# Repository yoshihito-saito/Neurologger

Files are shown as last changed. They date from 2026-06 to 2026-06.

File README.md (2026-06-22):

# WILD

**WILD** (Wireless, Interactive, Lightweight Datalogger) is an ultra-lightweight multimodal neurologger for long-term neural and behavioral recording in freely behaving animals. It combines local neural data logging, behavioral sensing, onboard processing, and responsive stimulation in a head-mounted platform designed for naturalistic and multi-animal experiments.

## Documentation

The documentation portal is built with MkDocs Material and is maintained through Markdown files in [`docs/`](docs/).

- [Getting Started](docs/getting-started/index.md)
- [Hardware](docs/hardware/index.md)
- [Software](docs/software/index.md)
- [Analysis](docs/analysis/index.md)
- [Community](docs/contributing.md)

## Platform Scope

- Local microSD electrophysiology recording with BLE-based control, synchronization, status, and low-bandwidth preview
- Closed-loop stimulation through embedded DSP and curated TinyML pipelines
- Current open-source 64-channel workflows, with Neuropixels-compatible and active-probe variants documented separately as research targets
- IMU, ultrasonic audio, camera, and digital event recording
- TinyML inference support through validated release-integrated models
- Long-term recording and multi-animal experiment workflows

## Repository Layout

| Path | Purpose |
| --- | --- |
| [`docs/`](docs/) | MkDocs documentation source |
| [Latest GitHub release](https://github.com/ayalab1/Neurologger/releases/latest) | Prebuilt device release images |
| [`Software/`](Software/) | WILD Console installers |
| [`Code/`](Code/) | MATLAB and Python analysis scripts |
| [`PCB/`](PCB/) | PCB fabrication and assembly files |
| [`3Dprint/`](3Dprint/) | Mechanical parts and CAD files |

## Local Documentation Build

```bash
pip install -r requirements.txt
mkdocs serve
```

The GitHub Pages workflow builds the site with:

```bash
mkdocs build --strict
```

## License

See [LICENSE](LICENSE).

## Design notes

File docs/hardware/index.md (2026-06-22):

# Hardware

Hardware documentation covers the WILD device architecture, onboard sensors, optional modules, mechanical assembly, power choices, and release-image compatibility for supported device revisions.

<div class="wild-grid wild-nav-grid">
  <a class="wild-card wild-card-link wild-card-compact" href="device-overview/">
    <div>
      <h3>Device</h3>
      <p>Architecture</p>
    </div>
  </a>
  <a class="wild-card wild-card-link wild-card-compact" href="onboard-sensors/">
    <div>
      <h3>Sensors</h3>
      <p>IMU, audio, camera</p>
    </div>
  </a>
  <a class="wild-card wild-card-link wild-card-compact" href="opto-module/">
    <div>
      <h3>Opto module</h3>
      <p>Stimulation</p>
    </div>
  </a>
  <a class="wild-card wild-card-link wild-card-compact" href="usb-board/">
    <div>
      <h3>USB-GPIO</h3>
      <p>Trigger alignment</p>
    </div>
  </a>
  <a class="wild-card wild-card-link wild-card-compact" href="mechanical/">
    <div>
    <h3>Mechanical</h3>
      <p>Mounts and enclosures</p>
    </div>
  </a>
  <a class="wild-card wild-card-link wild-card-compact" href="power/">
    <div>
    <h3>Power</h3>
      <p>Battery, SD, mode power</p>
    </div>
  </a>
  <a class="wild-card wild-card-link wild-card-compact" href="https://github.com/ayalab1/Neurologger/releases/latest">
    <div>
      <h3>Releases</h3>
      <p>Firmware images</p>
    </div>
  </a>
</div>

## Hardware Asset Map

| Hardware area | Repository path |
| --- | --- |
| Datalogger PCB | [PCB/Datalogger](https://github.com/ayalab1/Neurologger/tree/main/PCB/Datalogger) |
| Opto module | [PCB/Optomodule](https://github.com/ayalab1/Neurologger/tree/main/PCB/Optomodule) |
| Camera unit | [PCB/CameraUnit](https://github.com/ayalab1/Neurologger/tree/main/PCB/CameraUnit) |
| USB-GPIO board | [PCB/USBboard](https://github.com/ayalab1/Neurologger/tree/main/PCB/USBboard) |
| USB-GPIO firmware | [Firmware/WILD_USB_GPIO.hex](https://github.com/ayalab1/Neurologger/blob/main/Firmware/WILD_USB_GPIO.hex) |
| Opto-module firmware | [Firmware/Opto_module.hex](https://github.com/ayalab1/Neurologger/blob/main/Firmware/Opto_module.hex) |
| Mechanical parts | [3Dprint](https://github.com/ayalab1/Neurologger/tree/main/3Dprint) |
| Battery table | [LipoBattery_selection.csv](https://github.com/ayalab1/Neurologger/blob/main/docs/LipoBattery_selection.csv) |
| Prebuilt device images | [Latest GitHub release](https://github.com/ayalab1/Neurologger/releases/latest) |

## Manufacturing Workflow

For a new WILD device build, start with the [Fabrication](../fabrication.md) page. The workflow covers fabrication parameters, PCBA submission, special components, manual soldering notes, and first DFU image installation.

## Compatibility Record

Document the following for each supported WILD hardware build or dataset:

| Record | Why it matters |
| --- | --- |
| PCB or device revision | Distinguishes connector layout, sensor options, and supported release images. |
| Release tag and image filename | Ties behavior to a reproducible device image. |
| WILD Console version | Defines the export and control tool behavior used in the session. |
| SD-card model | Affects boot reliability and long-session write stability. |
| Battery model | Affects boot margin, runtime, and peak-load behavior. |
| Enabled modalities | States whether the session used ephys, IMU, audio, video, stimulation, or external sync. |

## Bring-Up Checklist

Before the first recording on a newly assembled WILD device:

1. Confirm that the PCB revision, assembly files, and intended release image match.
2. Use the USB-to-4-pin bench cable and USB power meter for the first power check.
3. Install the first validated `.hex` release image through WILD Console **Advanced** DFU update.
4. Confirm battery polarity and boot stability.
5. Confirm microSD insertion and basic discoverability.
6. Confirm BLE connection and synchronization state.
7. Run a short recording, export it, and verify the expected files before any animal session.

## Visual Asset Policy

Public hardware visuals should be traceable to real WILD material: device photographs, CAD or EDA exports, microscope images, measured drawings, software screenshots, or hand-authored diagrams derived from measured hardware. AI-generated device photographs or device-like renders are excluded from WILD hardware documentation.

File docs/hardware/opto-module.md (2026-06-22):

# Opto Module

The WILD opto-module is the optional stimulation hardware path for optical manipulation experiments. It should be documented separately from the logger board because supported stimulation behavior depends on the opto-module hardware, release image, wiring, and validation procedure.

## Hardware Assets

| Asset | Repository path |
| --- | --- |
| PCB fabrication files | [PCB/Optomodule/GerberFiles](https://github.com/ayalab1/Neurologger/tree/main/PCB/Optomodule/GerberFiles) |
| Drill files | [PCB/Optomodule/DrillFiles](https://github.com/ayalab1/Neurologger/tree/main/PCB/Optomodule/DrillFiles) |
| Assembly files | [PCB/Optomodule/Assembly](https://github.com/ayalab1/Neurologger/tree/main/PCB/Optomodule/Assembly) |
| Prebuilt module image | [Firmware/Opto_module.hex](https://github.com/ayalab1/Neurologger/blob/main/Firmware/Opto_module.hex) |

## Supported Operations

| Operation | Purpose | Validation |
| --- | --- | --- |
| Manual stimulation test | Confirm optical output and wiring before closed-loop use. | Use a bench photodiode, optical power meter, or other approved output check. |
| Closed-loop stimulation output | Deliver stimulation in response to WILD DSP, threshold, or TinyML state when supported by the release image. | Compare event files, stimulation markers, and observed output timing. |
| External trigger stimulation | Drive stimulation from external timing equipment when the experiment requires external coordination. | Record the external trigger and WILD event path for later alignment. |
| Parameter review | Confirm pulse width, intensity, channel selection, and enable state before the animal session. | Save release image, WILD Console version, and stimulation settings with the dataset. |

## Bring-Up Checks

Before connecting the opto-module to an animal-mounted device:

1. Confirm the opto-module PCB revision and compatible release image.
2. Inspect connector orientation and solder joints.
3. Confirm current limit, load, and optical output path on the bench.
4. Run a manual test pulse and record the measured output.
5. Confirm that stimulation markers are exported with the recording when stimulation timing is part of the analysis.

## Metadata

Record the opto-module PCB revision, release image, stimulation channel, optical output calibration, cable or connector path, and validation file. For closed-loop studies, also record the DSP or model state that generated each stimulation event.

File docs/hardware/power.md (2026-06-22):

# Power

Power planning is central to WILD experiments because battery selection, microSD choice, recording mode, selected preview signals, stimulation, and camera use all affect runtime.

## Power Architecture

The WILD device conditions the selected battery through a converter and regulator chain before powering analog acquisition, digital control, and peripheral subsystems. Battery choice should therefore follow validated hardware-revision guidance rather than a single nominal-voltage number.

Boot, microSD writes, camera use, stimulation, and live preview can create different peak-load conditions. Validate the complete experiment mode on the bench before using a battery in an animal session.

## Measured Device Modes

Representative WILD power modes are summarized here because they directly affect battery selection and runtime planning. Report these values together with the release image, SD-card model, battery, and enabled peripherals used for the session.

<div class="wild-spec-scroll" markdown="1">

| Power (mW) | Channels | Samples/s | Mode | Weight (g) | Video | Audio | Motion sensor | Processing |
| --- | ---: | ---: | --- | ---: | --- | --- | --- | --- |
| 0.11 | 0 | 0 | Sleep | 1.48 | - | - | - | - |
| 24.42 | 8 | 4.0e4 | Ephys, IMU | 1.48 | - | - | Accelerometer, gyroscope, magnetosensor | Spectral power, TinyML |
| 194.04 | 64 | 2.6e6 | Ephys, IMU | 1.48 | - | - | Accelerometer, gyroscope, magnetosensor | Spectral power, TinyML |
| 208.67 | 64 | 2.92e6 | Ephys, IMU, audio | 1.48 | - | 160 kHz ultrasonic audio path | Accelerometer, gyroscope, magnetosensor | Spectral power, TinyML |
| 245.28 | 64 | 5.48e6 | Ephys, IMU, audio, video | 1.48 | 320 x 320 px, 16 Hz | 160 kHz ultrasonic audio path | Accelerometer, gyroscope, magnetosensor | Spectral power, TinyML |

</div>

The table is a planning reference, not a substitute for bench validation. Current draw can change with release image, recording duration, SD-card behavior, battery voltage, preview state, stimulation, and camera configuration.

## Battery

The WILD device should use a battery approved for the specific hardware revision and experiment mode. Before mounting the device, confirm that the battery can boot the device without voltage sag, start recording, and sustain the planned sensors, preview state, stimulation, or camera load.

Battery examples

The [battery selection table](https://github.com/ayalab1/Neurologger/blob/main/docs/LipoBattery_selection.csv) provides baseline capacity and runtime-planning references.

## Battery Connector

The WILD device battery input uses the JST-SH connector orientation documented in the hardware setup workflow. The connector is part of the experiment record because polarity, strain relief, and repeated mating can affect boot stability and long-session reliability.

WILD connector orientation schematic

For each hardware revision, record:

- Battery connector type and orientation.
- Battery lead polarity as assembled.
- Whether the battery lead was modified, extended, or re-terminated.
- Any strain-relief method used between the battery, enclosure, and animal-mounted device.

Before a recording session, inspect the connector shell, solder joints, and battery lead for looseness or damage. Do not infer polarity from wire color alone; confirm the assembled connector orientation against the WILD hardware revision being used.

See [Hardware Setup](../getting-started/hardware-setup.md) for the first-device connector checklist.

## First Power Check

For a newly assembled WILD device, use the USB-to-4-pin bench cable and a USB power meter before connecting a battery. The first connection should draw less than 10 mA before a release image is installed; a higher or unstable current is a stop condition for solder-bridge and connector inspection.

The DFU mode-select pin can be temporarily shorted to VCC during USB connection to expose the `STM32-DFU` device for first image installation. Use the connector schematic, keep the short temporary, and verify the pin orientation before applying power.

## Battery Charger

The charger is external to the WILD recording path. Charge batteries with a single-cell lithium-polymer charger that matches the battery chemistry, capacity, connector, and manufacturer charge-current rating. Record the charger model when reporting runtime or power stability results.

The WILD device should not be treated as a battery charger unless a specific hardware revision and release note explicitly documents charging support. For the public workflow, charge and inspect the battery before connecting it to the WILD device.

Recommended charger record:

| Item | Record |
| --- | --- |
| Charger model | Identifies the charge circuit used before the session. |
| Battery model and capacity | Links runtime to the actual energy source. |
| Charge current | Helps interpret battery heating, aging, and boot margin. |
| Connector adapter | Documents any JST-SH adapter or lead conversion used between the charger and battery. |
| Pre-session check | Confirms battery voltage, connector condition, and absence of swelling or cable damage. |

## microSD Power

The microSD card is part of the power and reliability budget. Format cards with WILD Console before recording, and validate the selected card in the same sampling and modality mode planned for the experiment.

microSD power comparison

## Runtime Reporting

Runtime depends on sampling rate, active modalities, preview state, stimulation use, microSD-card model, battery capacity, and ambient conditions. When reporting a WILD recording mode, include:

- Release image.
- SD-card model and format state.
- Battery model and capacity.
- Sampling rate and enabled modalities.
- Preview state.
- Stimulation or TinyML state, if used.
- Session environment, especially for outdoor or long-duration recordings.

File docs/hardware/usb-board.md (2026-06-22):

# USB Board

The WILD USB-GPIO board is used for bench validation, external trigger logging, and timing integration with behavioral equipment. It provides a PC-connected GPIO path that can be used alongside WILD BLE control and logger-side digital inputs.

USB-GPIO board with IO0 to IO3 and USB interface labels

## Interface

The board exposes four external I/O channels, labeled `IO0` to `IO3`, and a USB connection to the host PC. The USB path is useful for recording external events at the PC, generating TTL outputs for external equipment, and validating synchronization behavior before animal recordings.

## Fabrication Files

USB-GPIO board manufacturing files are available in [`PCB/USBboard`](https://github.com/ayalab1/Neurologger/tree/main/PCB/USBboard).

| File | Purpose |
| --- | --- |
| [`WILD_USB_2026-06-18.zip`](https://github.com/ayalab1/Neurologger/blob/main/PCB/USBboard/WILD_USB_2026-06-18.zip) | Gerber package for PCB fabrication. |
| [`WILD_USB.xlsx`](https://github.com/ayalab1/Neurologger/blob/main/PCB/USBboard/WILD_USB.xlsx) | BOM workbook for assembly review. |
| [`WILD_USB.csv`](https://github.com/ayalab1/Neurologger/blob/main/PCB/USBboard/WILD_USB.csv) | BOM export for manufacturer upload or quick inspection. |
| [`WILD_USB.brd`](https://github.com/ayalab1/Neurologger/blob/main/PCB/USBboard/WILD_USB.brd) and [`WILD_USB.sch`](https://github.com/ayalab1/Neurologger/blob/main/PCB/USBboard/WILD_USB.sch) | Eagle board and schematic source files. |

## Windows Host Timing

The WILD device and the Windows acquisition PC use independent clocks. Keeping those clocks aligned matters when USB-GPIO trigger timestamps are merged with WILD logger events. Windows automatic time management does not calibrate drift against WILD time, and an automatic time correction can create an abrupt shift between the PC clock and the device clock during a recording.

For best synchronization accuracy with the USB-GPIO board on Windows, disable automatic time setting and automatic time-zone changes before the recording session. Download and run `TimeCalibrator` on the acquisition computer, then use the calibration record to correct PC-to-WILD time offset and drift after export.

Keep the raw USB-GPIO log, TimeCalibrator record, and corrected timestamp table with the WILD export so the synchronization correction can be audited later.

## Supported Operations

| Operation | Direction | Use case | Timing note |
| --- | --- | --- | --- |
| TTL input logging | External equipment -> USB-GPIO -> PC | Log camera, behavior, or stimulation trigger edges at the host PC. | Host timestamps must be aligned to WILD logger time before merging with neural data. |
| TTL output control | WILD or PC command -> PC -> USB-GPIO -> external equipment | Drive external cameras, stimulation controllers, or behavior systems. | Output timing includes BLE, PC scheduling, USB transfer, and GPIO latency when WILD initiates the command. |
| Periodic sync pulses | Shared pulse to USB-GPIO and WILD digital input | Estimate offset and drift between PC timestamps and WILD logger time. | Use repeated pulses across the recording, not only a start pulse. |
| Bench validation | PC plus WILD test setup | Check wiring, edge polarity, event capture, and software logging before animal sessions. | Keep a short validation recording with raw USB log and WILD export. |

See [GPIO-through-USB Trigger Alignment](../software/data-format.md#gpio-through-usb-trigger-alignment) for timestamp correction, drift monitoring, and the difference between incoming and outgoing trigger paths.

## Recommended Use

1. Assign channel names before the session, for example `camera_trigger`, `behavior_event`, `sync_pulse`, or `stim_marker`.
2. Confirm input or output direction for each channel.
3. Run a short bench pulse train through the same path used by the experiment.
4. Save the USB-GPIO log together with the WILD export.
5. Apply post-export correction before combining PC-side trigger times with WILD neural, IMU, audio, camera, or stimulation events.

## Metadata

Record the USB-GPIO board revision, connected channels, edge polarity, host software, WILD Console version, BLE controller path, and whether the board was used for input logging, output control, or both.

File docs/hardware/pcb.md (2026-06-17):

# Fabrication

The PCB manufacturing and assembly workflow is now documented as a top-level [Fabrication](../fabrication.md) page.

Use that page for board ordering parameters, PCBA files, special components, first DFU image installation, and post-assembly inspection.

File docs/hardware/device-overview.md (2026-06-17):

# Device Overview

The WILD device is a Wireless, Interactive, Lightweight Datalogger: an ultra-lightweight multimodal neurologger for freely behaving animals. It combines local neural data logging, auxiliary sensing, onboard processing, BLE configuration and status, synchronization support, and responsive stimulation.

WILD is not a BLE telemetry system. High-bandwidth neural data are recorded locally to microSD; wireless links are used for discovery, configuration, synchronization support, status, low-bandwidth preview, and online control commands.

The device is best understood as a head-mounted acquisition and control unit. Neural acquisition, auxiliary sensing, embedded processing, microSD storage, external I/O, and optional stimulation are handled on the device. The host computer or controller supports setup, timing coordination, status review, selected preview, command delivery, and export.

WILD device

## Functional Blocks

<div class="wild-functional-blocks" aria-label="WILD functional block diagram">
  <div class="wild-fb-group">
    <h3>Inputs</h3>
    <div class="wild-fb-card">Neural probe</div>
    <div class="wild-fb-card">IMU, audio, camera, and digital inputs</div>
  </div>
  <div class="wild-fb-group">
    <h3>Device core</h3>
    <div class="wild-fb-card wild-fb-primary">Analog front end</div>
    <div class="wild-fb-card wild-fb-primary">MCU and embedded DSP</div>
  </div>
  <div class="wild-fb-group">
    <h3>Local outputs</h3>
    <div class="wild-fb-card">microSD storage</div>
    <div class="wild-fb-card">Stimulation outputs</div>
  </div>
  <div class="wild-fb-group">
    <h3>Control links</h3>
    <div class="wild-fb-card">BLE control, sync, status, and preview</div>
    <div class="wild-fb-card">External I/O and USB setup</div>
  </div>
  <div class="wild-fb-group">
    <h3>Analysis</h3>
    <div class="wild-fb-card">MATLAB, Python, and spike sorting</div>
  </div>
</div>

## Device Interfaces

| Interface | Public documentation focus |
| --- | --- |
| Neural input | Standard 64-channel connector workflows and WILD flexible-probe workflows. |
| Local storage | Full-resolution neural, IMU, audio, camera, and event data are recorded to microSD. |
| Wireless control | BLE supports discovery, configuration, synchronization support, status checks, selected preview, and commands. |
| External I/O | Sync and control lines connect WILD devices with cameras, behavior systems, stimulation modules, and multi-device sessions. |
| Bench setup | USB and wired interfaces can support setup and validation workflows when high-bandwidth local monitoring is needed. |

Detailed sensor, opto-module, and USB-GPIO board notes are documented in the dedicated Hardware chapters.

## Current Public Scope

- The current open-source WILD release is the 64-channel local-storage neurologger workflow.
- Higher-performance Neuropixels-compatible and active-SPI-probe workflows are separate research and variant targets unless explicitly supported by a release note.
- Multi-device experiments use explicit synchronization workflows rather than BLE timestamps alone.
- Mass is configuration-dependent; report device-only mass, probe or module mass, battery mass, and complete implant mass separately.

## Core Specifications

| Category | Current WILD specification |
| --- | --- |
| Neural channels | 64 |
| Device mass | Approximately 1.5 g for the logger board, configuration-dependent |
| Board dimensions | 23.3 x 15.7 mm |
| MCU | Cortex-M4 class MCU for acquisition, embedded DSP, TinyML scheduling, and device control |
| Power input | Use release-specific approved battery options; internal rails are generated by a converter/regulator chain |
| Sampling rates | 1,250-20,000 Hz |
| ADC resolution | 16-bit electrophysiology and microphone data; 10-bit camera data |
| Storage | microSD, Class 10 or better; low-power endurance cards are preferred |
| Recommended cards | Samsung EVO older orange U1 generation or tested Lexar cards |
| BLE | Control link for discovery, synchronization support, status, selected preview, and low-bandwidth commands |
| IMU | BMX160, up to 500 Hz |
| USV microphone | SPH6611LR5H, approximately 1-80 kHz bandwidth |
| Camera | NanEye-C, 320 x 320 px, 16 FPS, 10-bit |
| Stimulation | Optional two-channel laser-diode stimulation module based on TPS6115x |

## Supported Modalities

- Local neural electrophysiology recording.
- Responsive closed-loop stimulation from onboard detection.
- IMU sensing and sensor fusion.
- Ultrasonic vocalization audio through ADC data.
- Head-mounted camera data through `misc.dat`.
- Digital input and synchronization signals.
- External I/O for synchronization, stimulation control, and integration with behavioral equipment.

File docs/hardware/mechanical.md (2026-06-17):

# Mechanical

Mechanical files are stored in the repository for baseplates, covers, and camera-related parts.

## Available Files

| Part | Repository path |
| --- | --- |
| Top cover | [WILD_TopCover.STL](https://github.com/ayalab1/Neurologger/blob/main/3Dprint/MouseCase/WILD_TopCover.STL) |
| Baseplate | [WILD_Baseplate.STL](https://github.com/ayalab1/Neurologger/blob/main/3Dprint/MouseCase/WILD_Baseplate.STL) |
| Camera baseplate | [WILD_Baseplate_Camera.STL](https://github.com/ayalab1/Neurologger/blob/main/3Dprint/MouseCase/WILD_Baseplate_Camera.STL) |
| Mouse-case CAD source | [Wild_Case.SLDPRT](https://github.com/ayalab1/Neurologger/blob/main/3Dprint/MouseCase/Wild_Case.SLDPRT) and [WILD_Case.f3d](https://github.com/ayalab1/Neurologger/blob/main/3Dprint/MouseCase/WILD_Case.f3d) |
| Cambridge NeuroTech probe assembly | [WILDAssemblyVertical.stp](https://github.com/ayalab1/Neurologger/blob/main/3Dprint/CambridgeNT_Probe/WILDAssemblyVertical.stp), [WILDAssemblyVertical.f3d](https://github.com/ayalab1/Neurologger/blob/main/3Dprint/CambridgeNT_Probe/WILDAssemblyVertical.f3d), and printable support parts in `3Dprint/CambridgeNT_Probe/` |

## Rendered Model Views

<div class="wild-grid two">
  <figure class="wild-image-frame">
    Rendered WILD mouse case model with baseplate and cover
    <figcaption class="wild-caption">Mouse-case render showing the baseplate and cover geometry for device protection and mounting.</figcaption>
  </figure>
  <figure class="wild-image-frame">
    Rendered vertical WILD assembly for Cambridge NeuroTech probe workflow
    <figcaption class="wild-caption">Vertical assembly render for the Cambridge NeuroTech probe workflow, useful for checking model orientation and enclosure clearance. Courtesy of Adam Lowet, UC Berkeley.</figcaption>
  </figure>
</div>

## Design Considerations

- Keep cable strain relief and connector access visible in photos.
- Document orientation of the baseplate relative to probes, stimulation leads, and camera modules.
- Include printing material, layer height, support recommendations, and post-processing steps.
- Add animal-specific mounting notes only after local approval and protocol review.

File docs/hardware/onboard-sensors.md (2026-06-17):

# Onboard Sensors

WILD sensor documentation describes the auxiliary channels recorded alongside neural data or used during bench validation. Treat each enabled sensor as part of the experiment configuration: record the release image, sampling mode, connected module, and whether the output was used for monitoring, downstream analysis, or both.

## IMU

The WILD device includes a 9-axis motion-sensor path for acceleration, gyroscope, and magnetic-field measurements. IMU data support motion-state review, behavioral segmentation, artifact inspection, and alignment with external tracking systems.

For reproducible datasets, document:

- IMU enable state.
- Configured sample rate.
- Axis orientation relative to the mounted device.
- Whether IMU channels were exported in `analogin.dat` or processed into `IMU.mat`.
- Any filtering, resampling, or coordinate transform applied after export.

## Camera

The head-mounted camera path supports synchronized behavioral context when video is enabled in the release image and hardware configuration. Camera payloads are recovered from local device storage during export; live preview is used for setup and focus checks rather than as the full-quality data source.

Record the camera hardware, release image, frame rate, working distance, illumination condition, and decode script version with each dataset.

### Camera Imaging Profile

Camera imaging profile at 4 mm, 8 mm, and 12 mm working distances

Use the camera imaging profile during bench setup to choose the working distance and focus range before mounting the camera module. Confirm the expected target distance with live preview before treating camera data as part of the experiment record.

## Microphone

The WILD microphone path uses the SPH6611LR5H ultrasonic microphone for vocalization and high-frequency acoustic recordings. In the documented WILD workflow, microphone data are sampled at 160 kHz, supporting acoustic content up to approximately 80 kHz when the analog path, sampling mode, and export settings are configured for USV recording.

The microphone ribbon assembly includes an embedded 10x amplifier stage before the logger input. Record whether the microphone ribbon and amplifier stage are present, the microphone orientation, and the release image used for acquisition.

For microphone sessions, document:

- Microphone model: SPH6611LR5H.
- Sampling rate: 160 kHz in the USV recording workflow.
- Approximate frequency response target: up to 80 kHz.
- Ribbon/amplifier configuration, including the embedded 10x amplifier stage.
- Audio export file path, decode script version, and any filtering or gain applied after export.

## Digital Inputs

Digital input channels are used for synchronization pulses, behavioral event markers, camera triggers, stimulation markers, or bench validation signals. These inputs are most useful when the same physical pulse is also recorded by the external system being aligned.

For timing-sensitive work, keep the raw digital input record and any generated event files. Post-export correction should preserve both raw event times and the corrected WILD-time event table.

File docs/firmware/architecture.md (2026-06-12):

# Firmware Architecture

The WILD firmware is organized around deterministic acquisition, local recording, BLE control, and optional closed-loop compute.

```mermaid
flowchart TD
  Boot[Bootloader] --> App[Application image]
  App --> Config[System parameters]
  App --> Acquire[Neural and sensor acquisition]
  Acquire --> DSP[Embedded DSP]
  DSP --> Stim[Stimulation control]
  Acquire --> Store[microSD writer]
  App --> BLE[BLE command, status, preview]
  Store --> Export[WILD_console export]
```

## Main Responsibilities

- Start from bootloader or application image.
- Validate and apply system parameters.
- Acquire neural and auxiliary channels.
- Write data to microSD in the WILD recording layout.
- Respond to BLE commands from WILD_console.
- Run online filters and closed-loop logic when enabled.
- Provide preview and state data for live monitoring.

## Recommended Documentation Additions

- Task and interrupt diagram.
- Timing budget for acquisition, SD writes, BLE preview, and DSP.
- Firmware state machine.
- Binary release checklist.

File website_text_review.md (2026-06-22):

# WILD Website Text Review Bundle

Generated from the current MkDocs Markdown source files, including the navigation pages and the built PCB compatibility page.

Use the Source file marker before each section to map edits back to the website source.

---

# Source file: docs/index.md

---
hide:
  - navigation
  - toc
---

<section class="wild-hero">
  <div>
    <h1>WILD: wireless neural recording and closed-loop control in freely behaving animals</h1>
    <p>The Wireless, Interactive, Lightweight Datalogger (WILD) is a head-mounted local-storage platform for neural recording and closed-loop experimental control in freely behaving small animals. The system combines multichannel electrophysiology, auxiliary behavioral sensing, onboard processing, microSD storage, wireless configuration, and validated stimulation workflows.</p>
    <div class="wild-actions">
      <a class="md-button md-button--primary" href="getting-started/">Get Started</a>
      <a class="md-button" href="hardware/">Hardware</a>
      <a class="md-button" href="software/">Software</a>
      <a class="md-button" href="https://github.com/ayalab1/Neurologger">GitHub</a>
    </div>
    <div class="wild-signal-row">
      <span>64-channel electrophysiology</span>
      <span>Closed-loop DSP</span>
      <span>9-axis IMU</span>
      <span>USV audio</span>
      <span>Head-mounted camera</span>
    </div>
  </div>
  <div class="wild-hero-media wild-hero-media-tiled">
    <figure class="wild-hero-tile wild-hero-device-tile">
      WILD wireless modular datalogger device
      <figcaption class="wild-caption">WILD integrates local neural recording, behavioral monitoring, embedded processing, microSD storage, wireless control, and stimulation support in a compact head-mounted platform.</figcaption>
    </figure>
    <figure class="wild-hero-tile wild-hero-ephys-tile">
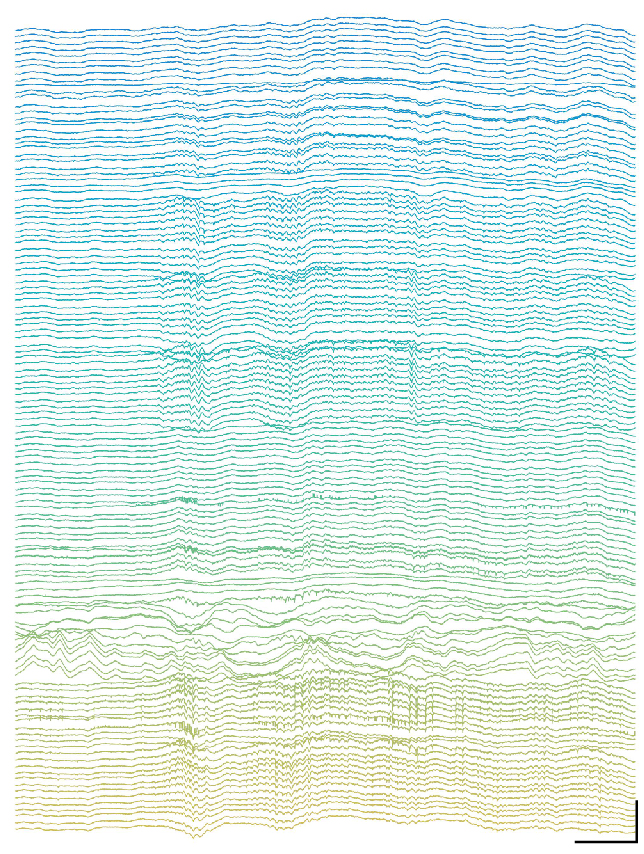
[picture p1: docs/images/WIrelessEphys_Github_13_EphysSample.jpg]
Example WILD electrophysiology recording workflow
      
    </figure>
  </div>
</section>

<section class="wild-section wild-paper-banner">
  <h2>Publication status</h2>
  <p>A manuscript describing the WILD platform is currently under review. This website provides public-facing documentation for the hardware files, release images, WILD Console usage, post-processing workflows, metadata requirements, and validation checks associated with the platform.</p>
  <p>Final peer-reviewed citation information will be added after publication. Until then, report the repository, release image, hardware revision, WILD Console version, SD card, battery, enabled modalities, and analysis scripts used for each dataset.</p>
</section>

<section class="wild-section">
  <h2>Why WILD?</h2>
  <div class="wild-grid wild-feature-grid">
    <div class="wild-card wild-feature-card">
      <h3>Naturalistic neuroscience</h3>
      <p>Record neural activity while animals explore, interact socially, vocalize, or move through large environments where tethered systems are limiting.</p>
    </div>
    <div class="wild-card wild-feature-card">
      <h3>Local full-resolution recording</h3>
      <p>High-bandwidth neural and multimodal data are written to onboard microSD storage. BLE is used for discovery, configuration, synchronization support, status, preview, and commands.</p>
    </div>
    <div class="wild-card wild-feature-card">
      <h3>Closed-loop control</h3>
      <p>Embedded DSP and curated TinyML workflows support device-local detection and responsive stimulation without requiring continuous full-bandwidth wireless streaming.</p>
    </div>
    <div class="wild-card wild-feature-card">
      <h3>Open and reproducible</h3>
      <p>Hardware files, release images, WILD Console installers, MATLAB scripts, Python tools, and documentation are organized for release-specific methods reporting.</p>
    </div>
  </div>
</section>

<section class="wild-section">
  <div class="wild-grid two">
    <div class="wild-card">
      <h2>Open-source release</h2>
      <p><strong>Included in the public workflow:</strong> 64-channel local-storage WILD recording, WILD Console on Windows, validated release images, optional stimulation workflows, and post-processing through documented MATLAB and Python scripts.</p>
      <p><strong>Not part of the stable public workflow:</strong> continuous full-bandwidth BLE telemetry, arbitrary runtime AI-model upload, and separate higher-performance research variants unless a release note explicitly supports them.</p>
    </div>
    <div class="wild-card">
      <h2>Reproducibility record</h2>
      <p>For each experiment, record the exact release tag, device image filename, hardware revision, WILD Console version, SD-card model, battery, enabled modalities, and analysis-script commit.</p>
      <p><a href="https://github.com/ayalab1/Neurologger/releases/latest">Open the latest GitHub release</a>.</p>
    </div>
  </div>
</section>

<section class="wild-zoom-tour" aria-label="WILD device zoom tour">
  <div class="wild-zoom-stage" aria-live="polite">
    <h2 id="wild-zoom-title">Embedded control at the headstage</h2>
    <p id="wild-zoom-description">The MCU, IMU, and board-level control electronics sit close to the animal, reducing external cabling while keeping timing-sensitive acquisition local.</p>
    <figure class="wild-zoom-frame">
      Real WILD device with labeled functional regions
      <figcaption id="wild-zoom-label">MCU and IMU</figcaption>
    </figure>
  </div>

  <div class="wild-zoom-scroll" aria-hidden="true">

  </div>
</section>

<section class="wild-section">
  <h2>Key capabilities</h2>
  <div class="wild-grid">
    <div class="wild-card">
      <h3>Electrophysiology</h3>
      <p>Up to 64 neural channels are recorded locally at release-configured sampling rates for downstream Intan-style analysis and spike sorting.</p>
    </div>
    <div class="wild-card">
      <h3>Behavioral sensing</h3>
      <p>IMU, digital inputs, ultrasonic audio, and head-mounted camera streams can be captured with the neural recording to support synchronized neuro-behavioral analysis.</p>
    </div>
    <div class="wild-card">
      <h3>Responsive stimulation</h3>
      <p>Onboard biomarker detection, DSP states, and curated model outputs can trigger stimulation in supported release images and validated hardware configurations.</p>
    </div>
    <div class="wild-card">
      <h3>Multi-device experiments</h3>
      <p>External I/O, digital events, and post-export alignment workflows support experiments involving multiple WILD devices and behavioral systems.</p>
    </div>
    <div class="wild-card">
      <h3>Field-ready workflow</h3>
      <p>Local storage, low-power modes, and wireless control make the platform suitable for long recordings and outdoor or large-arena experiments after bench validation.</p>
    </div>
  </div>
</section>

<section class="wild-section">
  <h2>Specification summary</h2>
  <p>The public WILD workflow combines local high-bandwidth recording with low-bandwidth wireless control and documented post-processing.</p>
  <div class="wild-spec-strip" aria-label="WILD device specification strip">
    <span>64 channels</span>
    <span>~1.48 g logger</span>
    <span>microSD logging</span>
    <span>BLE control</span>
    <span>9-axis IMU</span>
    <span>USV audio</span>
    <span>Head-mounted camera</span>
    <span>Closed-loop DSP</span>
  </div>
  <p class="wild-table-note">Mode-dependent power values are listed in <a href="hardware/power/#measured-device-modes">Hardware / Power</a>, together with release image, SD-card, and battery metadata.</p>
</section>

<section class="wild-section">
  <h2>System overview</h2>
  <p>A typical session moves from animal-mounted acquisition to local storage, synchronization, export, and offline analysis.</p>
  <div class="wild-system-panels">
    <div class="wild-flow wild-flow-vertical" aria-label="WILD system overview">
      <div>Animal</div>
      <div>Device</div>
      <div>Sensors</div>
      <div>Storage</div>
      <div>Synchronization</div>
      <div>Analysis</div>
    </div>
    <figure class="wild-image-frame wild-system-figure">
      WILD system diagram
    </figure>
  </div>
</section>

<section class="wild-section">
  <h2>Research highlights</h2>
  <div class="wild-grid wild-highlight-grid">
    <div class="wild-card wild-highlight-card">
      <h3>Outdoor recordings</h3>
      <p>Local storage and wireless control support electrophysiological recordings in large naturalistic environments where tethering is impractical.</p>
    </div>
    <div class="wild-card wild-highlight-card">
      <h3>Multi-animal experiments</h3>
      <p>Wired sync, BLE calibration, and clock-correction workflows coordinate multiple WILD devices and external behavioral systems.</p>
    </div>
    <div class="wild-card wild-highlight-card">
      <h3>Closed-loop ripple detection</h3>
      <p>DSP filters support ripple-band detection for responsive hippocampal experiments in validated release images.</p>
    </div>
    <div class="wild-card wild-highlight-card">
      <h3>Theta phase stimulation</h3>
      <p>Hilbert and filter modes support phase-aware online control designs when enabled and validated for the release image.</p>
    </div>
    <div class="wild-card wild-highlight-card">
      <h3>Multimodal behavior</h3>
      <p>IMU, video, USV, and neural data support studies of social interaction, navigation, and freely expressed behavior.</p>
    </div>
    <div class="wild-card wild-highlight-card">
      <h3>Open hardware iteration</h3>
      <p>The repository contains hardware files, validated release assets, WILD Console installers, and analysis scripts.</p>
    </div>
  </div>
</section>

<section class="wild-section wild-quickstart">
  <h2>Quick start</h2>
  <div class="wild-grid two">
    <div class="wild-card wild-step">
      <h3>1. Hardware setup</h3>
      <p>Check connectors, battery polarity, microSD card, probe cabling, sensor cabling, and the release image before the first recording.</p>
    </div>
    <div class="wild-card wild-step">
      <h3>2. Data acquisition</h3>
      <p>Use WILD Console for BLE connection, synchronization support, recording configuration, closed-loop settings, and local logging startup.</p>
    </div>
    <div class="wild-card wild-step">
      <h3>3. Data analysis</h3>
      <p>Convert exported recordings into Intan-style files, IMU outputs, camera or audio media, and spike-sorting inputs.</p>
    </div>
  </div>
  <p class="wild-table-note">Recommended first target: complete a short bench recording, export the folder, confirm `amplifier.dat`, `analogin.dat`, `time.dat`, `info.rhd`, and `CE_params.bin`, then open the result with the documented MATLAB or Python workflow.</p>
</section>

<section class="wild-section">
  <h2>Publication and citation</h2>
  <div class="wild-grid two">
    <div class="wild-card">
      <h3>Publication status</h3>
      <p>A manuscript describing the WILD platform is currently under review. Final citation information, including journal, DOI, volume, issue, and page details, will be added only after publication.</p>
    </div>
    <div class="wild-card">
      <h3>Repository and release versions</h3>
      <p>Before publication, cite the repository or release record and report the hardware revision, release image, WILD Console version, SD-card model, battery configuration, enabled modalities, and analysis scripts used for each dataset.</p>
    </div>
  </div>

```bibtex
@misc{wild_repository,
  title        = {WILD: Wireless, Interactive, Lightweight Datalogger},
  author       = {Zhao, Zifang and Chang, Hongyu and Paudel, Praveen and Park, Jaehyo and Liu, Can and Aurelio, Maria Q. and Oliva, Azahara and Fernandez-Ruiz, Antonio},
  howpublished = {\url{https://github.com/ayalab1/Neurologger}},
  note         = {Public documentation and release files. Report the release tag, device image, hardware revision, WILD Console version, and analysis-script commit used in the experiment.},
  year         = {2026}
}
```
</section>

<section class="wild-section">
  <h2>Community</h2>
  <div class="wild-grid">
    <div class="wild-card">
      <h3>GitHub</h3>
      <p><a href="https://github.com/ayalab1/Neurologger">Browse hardware files, release images, WILD Console installers, and analysis scripts.</a></p>
    </div>
    <div class="wild-card">
      <h3>Issues and pull requests</h3>
      <p>Use GitHub issues for reproducible bugs or documentation gaps, and pull requests for tested fixes, examples, and compatibility updates.</p>
    </div>
    <div class="wild-card">
      <h3>Contributing</h3>
      <p><a href="contributing/">Issues and pull requests are appropriate for hardware notes, analysis examples, compatibility reports, and documentation improvements.</a></p>
    </div>
  </div>
</section>

---

# Source file: docs/getting-started/index.md

# Getting Started

Start here if you are setting up a WILD device for the first time or reproducing the public WILD workflow associated with the manuscript under review.

<div class="wild-grid wild-nav-grid">
  <a class="wild-card wild-card-link wild-card-compact" href="hardware-setup/">
    <div>
      <h3>Hardware setup</h3>
      <p>Prepare device</p>
    </div>
  </a>
  <a class="wild-card wild-card-link wild-card-compact" href="data-acquisition/">
    <div>
      <h3>Data acquisition</h3>
      <p>Record and export</p>
    </div>
  </a>
  <a class="wild-card wild-card-link wild-card-compact" href="data-analysis/">
    <div>
      <h3>Data analysis</h3>
      <p>Convert outputs</p>
    </div>
  </a>
</div>

## Before You Begin

- Windows 10 or later for WILD Console.
- Bluetooth 4.0 or later for BLE control.
- A tested microSD card installed in the WILD device. Use Samsung EVO series or tested Lexar cards for first recordings; some SanDisk cards may be unreliable in specific WILD operating modes.
- A battery that can boot the WILD device and sustain the planned recording mode.
- The correct release image for the hardware revision and experiment mode.
- Windows clock preparation before timing-sensitive recordings: disable automatic time setting and automatic time-zone changes, run `TimeCalibrator`, and keep the calibration record for post-export offset and drift correction.

!!! warning "Recording prerequisite: Windows clock preparation"
    WILD logger time and PC system time are independent clocks. Windows automatic time correction can create an abrupt PC-clock step during a session, so timing-sensitive recordings should not begin until Windows automatic time adjustment is disabled and `TimeCalibrator` has been run.

## Repository Assets

| Asset | Location |
| --- | --- |
| Prebuilt device images | [Latest GitHub release](https://github.com/ayalab1/Neurologger/releases/latest) |
| WILD Console installers | [Latest GitHub release](https://github.com/ayalab1/Neurologger/releases/latest) |
| Fabrication guide | [Fabrication](../fabrication.md) |
| Board source files | [PCB](https://github.com/ayalab1/Neurologger/tree/main/PCB) |
| 3D-print files | [3Dprint](https://github.com/ayalab1/Neurologger/tree/main/3Dprint) |
| MATLAB and Python analysis scripts | [Code](https://github.com/ayalab1/Neurologger/tree/main/Code) |

!!! tip "Recommended first path"
    Start with Hardware Setup, then Data Acquisition, then Data Analysis. The SD card, battery, release image, and boot state provide the baseline for troubleshooting.

## First Successful Dry Run

**Goal:** complete a short bench recording and confirm that the public export and analysis path works before changing advanced settings.

**Minimum output folder:**

- `amplifier.dat`
- `analogin.dat`
- `time.dat`
- `info.rhd`
- `CE_params.bin`

**Optional outputs, depending on mode:**

- `adc.dat` for audio workflows.
- `misc.dat` for camera workflows.
- `device_event.*.evt` files after MATLAB preprocessing.
- `IMU.mat` after IMU processing.

**Success criteria:**

1. The WILD device is discovered and connected in WILD Console.
2. A short recording starts and stops cleanly.
3. SD-card export completes without missing-core-file errors.
4. The exported folder contains the expected files for the recording mode.
5. MATLAB or Python post-processing runs without manual file repair.

---

# Source file: docs/getting-started/hardware-setup.md

# Hardware Setup

This checklist covers the physical preparation required before connecting WILD to software.

## Device and Connectors

Connector images identify the stimulation, auxiliary, sensor, sync, and battery interfaces before board power-up.

WILD connector overview

The connector-orientation schematic below highlights the power, ground, and USB data-line positions used during the first hardware check. Confirm the actual connector orientation on the assembled WILD device before applying power.

WILD connector orientation schematic

The WILD device uses these connectors to support local acquisition, storage, wireless control, synchronization, and optional stimulation in a compact head-mounted unit. Before powering the device, confirm which interfaces are required for the planned session.

## Preparation Checklist

1. Inspect the PCB and connectors for visible damage.
2. Confirm battery polarity on the JST-SH connector.
3. Insert a tested microSD card.
4. Confirm the recording probe or flexible-probe connection.
5. Confirm the stimulation output, IMU, microphone, camera, and external-sync connections needed for the experiment.
6. Confirm that the device is running the expected released device image.

## New Device Bring-Up

For a newly assembled WILD device, complete the bench power and programming checks before connecting a battery or probe.

1. Prepare a 4-pin JST-SH 1.0 mm cable using the connector orientation shown above. Pre-crimped JST-SH wire leads or equivalent lab-qualified leads can be used if the polarity and pin order are verified before connection.
2. Build a USB-to-4-pin test cable by soldering the JST-SH lead to a USB-A connector breakout or equivalent bench-supply adapter. Record the adapter type in local bring-up notes if the cable will be reused.
3. Insert a USB power meter between the PC or USB supply and the WILD device.
4. Connect the WILD device without a battery and check the first current reading. A current below 10 mA is the expected first-pass check for no obvious short circuit.
5. If current is higher than expected, disconnect the device and inspect the power connector, regulator area, microSD socket, and fine-pitch solder joints before continuing.
6. To enter DFU mode, momentarily short the DFU mode-select pin to VCC with metal tweezers while connecting USB. Use the connector schematic and avoid shorting adjacent pins.
7. Confirm that Windows detects an `STM32-DFU` device. If needed, install the ST DFU driver from [STSW-STM32080](https://www.st.com/en/development-tools/stsw-stm32080.html).
8. In WILD Console, open the **Advanced** tab and use the DFU update pipeline to install the latest validated `.hex` release image for the hardware revision.
9. After the first release image is installed, later supported updates can be performed through microSD when the release notes document that path.

Detailed board-ordering, assembly, and special-component notes are listed in [Fabrication](../fabrication.md).

## microSD Card

Format the card from WILD Console before recording. The microSD card affects both reliability and power draw.

microSD power comparison

Battery and SD-card guidance are part of the experimental protocol, not optional accessory setup.

Battery examples

## Released Device Image

Public setup documentation is based on prebuilt WILD release images. Each release image is matched to a hardware revision and experimental configuration. Keep the release tag and image filename in dataset metadata.

Release images are distributed through the [latest GitHub release](https://github.com/ayalab1/Neurologger/releases/latest). Follow the release notes for the specific image used in the experiment.

Treat the released device image as part of the hardware setup record. The WILD device, WILD Console version, SD card, battery, and analysis scripts should all be traceable to the dataset.

---

# Source file: docs/getting-started/data-acquisition.md

# Data Acquisition

WILD Console is the main operator interface for BLE connection, synchronization support, recording configuration, selected live preview, closed-loop control, and SD-card export.

WILD is a local-storage neurologger. High-bandwidth neural and multimodal data are written to the device microSD card. BLE supports setup, timing calibration, status messages, command delivery, and selected preview signals.

The current public workflow uses WILD Console on Windows. Full-resolution recordings are recovered from the microSD card.

The WILD device does not need continuous full-bandwidth wireless streaming to preserve the recording. Keep BLE connected when the session needs online preview, parameter changes, or live commands. Otherwise, use BLE for setup and timing coordination, then recover the full dataset from the microSD card.

!!! tip "First-session scope"
    For the first dry run, use only the minimum path needed to connect, record, stop, and export. Leave closed-loop, camera, stimulation, GPIO, and advanced parameter panels unchanged until the basic local-storage workflow is confirmed.

## Recording Prerequisites

Before starting a recording that will use PC-side timestamps, USB-GPIO triggers, camera triggers, behavior events, or multi-device alignment:

1. Disable Windows automatic time setting and automatic time-zone changes.
2. Run `TimeCalibrator` on the acquisition computer.
3. Keep the TimeCalibrator record with the WILD export.
4. Use the calibration record after export to correct PC-to-WILD time offset and drift.

WILD and the PC use independent clocks. Windows automatic time management does not calibrate PC drift against the WILD device clock, and an automatic correction can introduce an abrupt shift between PC time and WILD logger time during a recording.

## First-Pass Button Path

For a basic dry run, only a small part of WILD Console is needed. The closed-loop, camera, stimulation, GPIO, and advanced parameter panels can stay unchanged until the device connects, synchronizes, records, and exports reliably.

The online and live figures below are runtime screenshots from WILD Console during hardware sessions. Some window-title or device-list strings may still show older internal labels; the public documentation uses the WILD name consistently.

<div class="wild-operator-path">
  <div class="wild-operator-step">
    <span class="wild-button-label">Online tab</span>
    <p><strong>Connect to the device.</strong> Work in the Online tab for BLE discovery, synchronization, preview, and recording control.</p>
  </div>
  <div class="wild-operator-step">
    <span class="wild-button-label">Rescan</span>
    <p><strong>Find nearby WILD devices.</strong> If the device is not listed, rescan after confirming power, battery, and BLE status.</p>
  </div>
  <div class="wild-operator-step">
    <span class="wild-button-label">Device List</span>
    <p><strong>Select the target logger.</strong> The selected row updates device information, available space, and connection state.</p>
  </div>
  <div class="wild-operator-step">
    <span class="wild-button-label primary">Connect</span>
    <p><strong>Open the BLE session.</strong> Wait for device-state and synchronization labels before starting a recording.</p>
  </div>
  <div class="wild-operator-step">
    <span class="wild-button-label primary">Recording Start</span>
    <p><strong>Start local logging.</strong> Full-resolution data are written to the device microSD card, not streamed continuously over BLE.</p>
  </div>
  <div class="wild-operator-step">
    <span class="wild-button-label">Recording Stop</span>
    <p><strong>Close the recording cleanly.</strong> Stop before removing power or taking out the microSD card.</p>
  </div>
  <div class="wild-operator-step">
    <span class="wild-button-label">Offline tab</span>
    <p><strong>Move to export after recording.</strong> Insert the microSD card into the PC and use the Offline tab for SD-card download.</p>
  </div>
  <div class="wild-operator-step">
    <span class="wild-button-label primary">Save to Disk</span>
    <p><strong>Export the recording folder.</strong> WILD Console decodes the SD-card recording into public analysis files.</p>
  </div>
</div>

<p class="wild-operator-note">
  First-session rule: ignore <span class="wild-button-label muted">Closed-loop</span>, <span class="wild-button-label muted">Camera</span>, <span class="wild-button-label muted">Advanced</span>, and parameter panels until a simple recording can be started, stopped, and exported.
</p>

WILD Console runtime screenshot during connected acquisition

## Connect

1. Launch `WILD Console_EXE_PLACEHOLDER`.
2. Click <span class="wild-button-label">Rescan</span> if the device is not listed.
3. Select the WILD device from <span class="wild-button-label">Device List</span>.
4. Click <span class="wild-button-label primary">Connect</span> and wait for device-state and synchronization updates.
5. Confirm that the TX/RX indicators update. If BLE connects but synchronization does not start, check the microSD card and timing setup first.

**Expected signs of success**

- The device appears in the list after rescan.
- The selected row updates device information.
- Connect succeeds without repeated disconnect loops.
- Status labels move past discovery into an active connected state.

## Record

1. Confirm the expected sampling speed and channel count.
2. Leave closed-loop and camera settings unchanged unless the experiment needs them.
3. Use `Wait for start` only when coordinating multiple WILD Console instances.
4. Click <span class="wild-button-label primary">Recording Start</span> to begin local logging on the device.
5. Click <span class="wild-button-label">Recording Stop</span> when the experiment is complete.

**Expected signs of success**

- Recording starts without a parameter or storage error.
- Session duration advances normally.
- The device remains stable through stop.
- Exported files are longer than a trivial test header and have plausible file sizes.

## Field Validation

Before a field or multi-animal session, run a short dry run with every WILD device that will be used.

1. Connect each device and confirm it reaches the synchronized state.
2. Start and stop a short local recording on each device.
3. Export the SD card immediately and confirm expected duration, file size, and representative channels.
4. Use the release image specified for the experiment and hardware revision.
5. For multi-device sessions, repeat the dry run with the planned start order, external I/O wiring, and any camera or TTL sync source attached.

A connected or synchronized GUI state is not proof that data were written for the full intended duration. Treat unexpectedly short files, stalled file-size indicators, unstable offsets, frame drops, or missing channels as blockers before animal recordings.

## Live Display

The real-time view supports selected neural previews, auxiliary signals, IMU and DSP states, stimulation triggers, and threshold overlays. See [Live Visualization](../software/live-visualization.md) for the runtime preview screenshot and display controls.

Disable preview to save power and BLE bandwidth when live monitoring is not needed. Recover full-resolution recording data from the microSD card after the session.

## Download

Insert the SD card and click <span class="wild-button-label primary">Save to Disk</span>. WILD Console exports recordings into timestamped folders with neural, auxiliary, ADC, camera, metadata, and parameter files.

**Expected signs of success**

- Export finishes without stopping at the first folder.
- Core files appear in the export folder: `amplifier.dat`, `analogin.dat`, `CE_params.bin`.
- `time.dat` and `info.rhd` are generated by the documented preprocessing path.
- Optional `adc.dat` and `misc.dat` appear only when audio or camera were enabled.

<p class="wild-operator-note">
  Normal export does not require the red maintenance buttons. <span class="wild-button-label warning">Quick Format</span> is only for preparing a known empty card, and release-image maintenance is outside the routine recording path.
</p>

WILD Console runtime screenshot of the offline export workflow

## Common Blockers

| Symptom | First check |
| --- | --- |
| Device not listed after rescan | Battery, power, BLE discoverability, and whether the expected release image is installed. |
| BLE connects but synchronization never settles | microSD presence, timing wiring, and whether the session is waiting on external sync conditions. |
| Recording starts but export is unexpectedly short | Stop sequence, SD-card write stability, battery stability, and whether the device remained powered through the run. |
| Export folder is missing expected files | Recording mode, whether audio or camera were enabled, and whether preprocessing was run after export. |
| Preview is unstable | Treat preview as optional; confirm local recording first, then revisit BLE preview bandwidth or adapter quality. |

---

# Source file: docs/getting-started/data-analysis.md

# Data Analysis

The repository includes MATLAB and Python scripts for converting WILD recordings into analysis-ready files.

## Standard Post-processing

1. Export data from WILD Console.
2. Run `WILD_PreProcess.m` to generate corrected headers and timing files.
3. Run `WILD_processIMU.m` for IMU processing.
4. Run `WILD_VideoDecodewAudio.py` or the folder variants for camera recordings.
5. Prepare spike-sorting inputs from `amplifier.dat`.

## Script Locations

| Task | Script |
| --- | --- |
| Header and time correction | [`WILD_PreProcess.m`](https://github.com/ayalab1/Neurologger/blob/main/Code/WILD_PreProcess.m) |
| IMU processing | [`WILD_processIMU.m`](https://github.com/ayalab1/Neurologger/blob/main/Code/WILD_processIMU.m) |
| Camera decode with audio | [`WILD_VideoDecodewAudio.py`](https://github.com/ayalab1/Neurologger/blob/main/Code/WILD_VideoDecodewAudio.py) |
| Intan header generation | [`WILD_genIntanHeader.m`](https://github.com/ayalab1/Neurologger/blob/main/Code/WILD_genIntanHeader.m) |

!!! note
    Keep raw SD exports unchanged. Run conversion scripts into a separate analysis folder so the original recording can be reprocessed if metadata or analysis settings change.

---

# Source file: docs/hardware/index.md

# Hardware

Hardware documentation covers the WILD device architecture, onboard sensors, optional modules, mechanical assembly, power choices, and release-image compatibility for supported device revisions.

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

## Hardware Asset Map

| Hardware area | Repository path |
| --- | --- |
| Datalogger PCB | [PCB/Datalogger](https://github.com/ayalab1/Neurologger/tree/main/PCB/Datalogger) |
| Opto module | [PCB/Optomodule](https://github.com/ayalab1/Neurologger/tree/main/PCB/Optomodule) |
| Camera unit | [PCB/CameraUnit](https://github.com/ayalab1/Neurologger/tree/main/PCB/CameraUnit) |
| USB-GPIO board | [PCB/USBboard](https://github.com/ayalab1/Neurologger/tree/main/PCB/USBboard) |
| USB-GPIO firmware | [Firmware/WILD_USB_GPIO.hex](https://github.com/ayalab1/Neurologger/blob/main/Firmware/WILD_USB_GPIO.hex) |
| Opto-module firmware | [Firmware/Opto_module.hex](https://github.com/ayalab1/Neurologger/blob/main/Firmware/Opto_module.hex) |
| Mechanical parts | [3Dprint](https://github.com/ayalab1/Neurologger/tree/main/3Dprint) |
| Battery table | [LipoBattery_selection.csv](https://github.com/ayalab1/Neurologger/blob/main/docs/LipoBattery_selection.csv) |
| Prebuilt device images | [Latest GitHub release](https://github.com/ayalab1/Neurologger/releases/latest) |

## Manufacturing Workflow

For a new WILD device build, start with the [Fabrication](../fabrication.md) page. The workflow covers fabrication parameters, PCBA submission, special components, manual soldering notes, and first DFU image installation.

## Compatibility Record

Document the following for each supported WILD hardware build or dataset:

| Record | Why it matters |
| --- | --- |
| PCB or device revision | Distinguishes connector layout, sensor options, and supported release images. |
| Release tag and image filename | Ties behavior to a reproducible device image. |
| WILD Console version | Defines the export and control tool behavior used in the session. |
| SD-card model | Affects boot reliability and long-session write stability. |
| Battery model | Affects boot margin, runtime, and peak-load behavior. |
| Enabled modalities | States whether the session used ephys, IMU, audio, video, stimulation, or external sync. |

## Bring-Up Checklist

Before the first recording on a newly assembled WILD device:

1. Confirm that the PCB revision, assembly files, and intended release image match.
2. Use the USB-to-4-pin bench cable and USB power meter for the first power check.
3. Install the first validated `.hex` release image through WILD Console **Advanced** DFU update.
4. Confirm battery polarity and boot stability.
5. Confirm microSD insertion and basic discoverability.
6. Confirm BLE connection and synchronization state.
7. Run a short recording, export it, and verify the expected files before any animal session.

## Visual Asset Policy

Public hardware visuals should be traceable to real WILD material: device photographs, CAD or EDA exports, microscope images, measured drawings, software screenshots, or hand-authored diagrams derived from measured hardware. AI-generated device photographs or device-like renders are excluded from WILD hardware documentation.

---

# Source file: docs/hardware/pcb.md

# Fabrication

The PCB manufacturing and assembly workflow is now documented as a top-level [Fabrication](../fabrication.md) page.

Use that page for board ordering parameters, PCBA files, special components, first DFU image installation, and post-assembly inspection.

---

# Source file: docs/hardware/device-overview.md

# Device Overview

The WILD device is a Wireless, Interactive, Lightweight Datalogger: an ultra-lightweight multimodal neurologger for freely behaving animals. It combines local neural data logging, auxiliary sensing, onboard processing, BLE configuration and status, synchronization support, and responsive stimulation.

WILD is not a BLE telemetry system. High-bandwidth neural data are recorded locally to microSD; wireless links are used for discovery, configuration, synchronization support, status, low-bandwidth preview, and online control commands.

The device is best understood as a head-mounted acquisition and control unit. Neural acquisition, auxiliary sensing, embedded processing, microSD storage, external I/O, and optional stimulation are handled on the device. The host computer or controller supports setup, timing coordination, status review, selected preview, command delivery, and export.

WILD device

## Functional Blocks

<div class="wild-functional-blocks" aria-label="WILD functional block diagram">
  <div class="wild-fb-group">
    <h3>Inputs</h3>
    <div class="wild-fb-card">Neural probe</div>
    <div class="wild-fb-card">IMU, audio, camera, and digital inputs</div>
  </div>
  <div class="wild-fb-group">
    <h3>Device core</h3>
    <div class="wild-fb-card wild-fb-primary">Analog front end</div>
    <div class="wild-fb-card wild-fb-primary">MCU and embedded DSP</div>
  </div>
  <div class="wild-fb-group">
    <h3>Local outputs</h3>
    <div class="wild-fb-card">microSD storage</div>
    <div class="wild-fb-card">Stimulation outputs</div>
  </div>
  <div class="wild-fb-group">
    <h3>Control links</h3>
    <div class="wild-fb-card">BLE control, sync, status, and preview</div>
    <div class="wild-fb-card">External I/O and USB setup</div>
  </div>
  <div class="wild-fb-group">
    <h3>Analysis</h3>
    <div class="wild-fb-card">MATLAB, Python, and spike sorting</div>
  </div>
</div>

## Device Interfaces

| Interface | Public documentation focus |
| --- | --- |
| Neural input | Standard 64-channel connector workflows and WILD flexible-probe workflows. |
| Local storage | Full-resolution neural, IMU, audio, camera, and event data are recorded to microSD. |
| Wireless control | BLE supports discovery, configuration, synchronization support, status checks, selected preview, and commands. |
| External I/O | Sync and control lines connect WILD devices with cameras, behavior systems, stimulation modules, and multi-device sessions. |
| Bench setup | USB and wired interfaces can support setup and validation workflows when high-bandwidth local monitoring is needed. |

Detailed sensor, opto-module, and USB-GPIO board notes are documented in the dedicated Hardware chapters.

## Current Public Scope

- The current open-source WILD release is the 64-channel local-storage neurologger workflow.
- Higher-performance Neuropixels-compatible and active-SPI-probe workflows are separate research and variant targets unless explicitly supported by a release note.
- Multi-device experiments use explicit synchronization workflows rather than BLE timestamps alone.
- Mass is configuration-dependent; report device-only mass, probe or module mass, battery mass, and complete implant mass separately.

## Core Specifications

| Category | Current WILD specification |
| --- | --- |
| Neural channels | 64 |
| Device mass | Approximately 1.5 g for the logger board, configuration-dependent |
| Board dimensions | 23.3 x 15.7 mm |
| MCU | Cortex-M4 class MCU for acquisition, embedded DSP, TinyML scheduling, and device control |
| Power input | Use release-specific approved battery options; internal rails are generated by a converter/regulator chain |
| Sampling rates | 1,250-20,000 Hz |
| ADC resolution | 16-bit electrophysiology and microphone data; 10-bit camera data |
| Storage | microSD, Class 10 or better; low-power endurance cards are preferred |
| Recommended cards | Samsung EVO older orange U1 generation or tested Lexar cards |
| BLE | Control link for discovery, synchronization support, status, selected preview, and low-bandwidth commands |
| IMU | BMX160, up to 500 Hz |
| USV microphone | SPH6611LR5H, approximately 1-80 kHz bandwidth |
| Camera | NanEye-C, 320 x 320 px, 16 FPS, 10-bit |
| Stimulation | Optional two-channel laser-diode stimulation module based on TPS6115x |

## Supported Modalities

- Local neural electrophysiology recording.
- Responsive closed-loop stimulation from onboard detection.
- IMU sensing and sensor fusion.
- Ultrasonic vocalization audio through ADC data.
- Head-mounted camera data through `misc.dat`.
- Digital input and synchronization signals.
- External I/O for synchronization, stimulation control, and integration with behavioral equipment.

---

# Source file: docs/hardware/onboard-sensors.md

# Onboard Sensors

WILD sensor documentation describes the auxiliary channels recorded alongside neural data or used during bench validation. Treat each enabled sensor as part of the experiment configuration: record the release image, sampling mode, connected module, and whether the output was used for monitoring, downstream analysis, or both.

## IMU

The WILD device includes a 9-axis motion-sensor path for acceleration, gyroscope, and magnetic-field measurements. IMU data support motion-state review, behavioral segmentation, artifact inspection, and alignment with external tracking systems.

For reproducible datasets, document:

- IMU enable state.
- Configured sample rate.
- Axis orientation relative to the mounted device.
- Whether IMU channels were exported in `analogin.dat` or processed into `IMU.mat`.
- Any filtering, resampling, or coordinate transform applied after export.

## Camera

The head-mounted camera path supports synchronized behavioral context when video is enabled in the release image and hardware configuration. Camera payloads are recovered from local device storage during export; live preview is used for setup and focus checks rather than as the full-quality data source.

Record the camera hardware, release image, frame rate, working distance, illumination condition, and decode script version with each dataset.

### Camera Imaging Profile

Camera imaging profile at 4 mm, 8 mm, and 12 mm working distances

Use the camera imaging profile during bench setup to choose the working distance and focus range before mounting the camera module. Confirm the expected target distance with live preview before treating camera data as part of the experiment record.

## Microphone

The WILD microphone path uses the SPH6611LR5H ultrasonic microphone for vocalization and high-frequency acoustic recordings. In the documented WILD workflow, microphone data are sampled at 160 kHz, supporting acoustic content up to approximately 80 kHz when the analog path, sampling mode, and export settings are configured for USV recording.

The microphone ribbon assembly includes an embedded 10x amplifier stage before the logger input. Record whether the microphone ribbon and amplifier stage are present, the microphone orientation, and the release image used for acquisition.

For microphone sessions, document:

- Microphone model: SPH6611LR5H.
- Sampling rate: 160 kHz in the USV recording workflow.
- Approximate frequency response target: up to 80 kHz.
- Ribbon/amplifier configuration, including the embedded 10x amplifier stage.
- Audio export file path, decode script version, and any filtering or gain applied after export.

## Digital Inputs

Digital input channels are used for synchronization pulses, behavioral event markers, camera triggers, stimulation markers, or bench validation signals. These inputs are most useful when the same physical pulse is also recorded by the external system being aligned.

For timing-sensitive work, keep the raw digital input record and any generated event files. Post-export correction should preserve both raw event times and the corrected WILD-time event table.

---

# Source file: docs/hardware/opto-module.md

# Opto Module

The WILD opto-module is the optional stimulation hardware path for optical manipulation experiments. It should be documented separately from the logger board because supported stimulation behavior depends on the opto-module hardware, release image, wiring, and validation procedure.

## Hardware Assets

| Asset | Repository path |
| --- | --- |
| PCB fabrication files | [PCB/Optomodule/GerberFiles](https://github.com/ayalab1/Neurologger/tree/main/PCB/Optomodule/GerberFiles) |
| Drill files | [PCB/Optomodule/DrillFiles](https://github.com/ayalab1/Neurologger/tree/main/PCB/Optomodule/DrillFiles) |
| Assembly files | [PCB/Optomodule/Assembly](https://github.com/ayalab1/Neurologger/tree/main/PCB/Optomodule/Assembly) |
| Prebuilt module image | [Firmware/Opto_module.hex](https://github.com/ayalab1/Neurologger/blob/main/Firmware/Opto_module.hex) |

## Supported Operations

| Operation | Purpose | Validation |
| --- | --- | --- |
| Manual stimulation test | Confirm optical output and wiring before closed-loop use. | Use a bench photodiode, optical power meter, or other approved output check. |
| Closed-loop stimulation output | Deliver stimulation in response to WILD DSP, threshold, or TinyML state when supported by the release image. | Compare event files, stimulation markers, and observed output timing. |
| External trigger stimulation | Drive stimulation from external timing equipment when the experiment requires external coordination. | Record the external trigger and WILD event path for later alignment. |
| Parameter review | Confirm pulse width, intensity, channel selection, and enable state before the animal session. | Save release image, WILD Console version, and stimulation settings with the dataset. |

## Bring-Up Checks

Before connecting the opto-module to an animal-mounted device:

1. Confirm the opto-module PCB revision and compatible release image.
2. Inspect connector orientation and solder joints.
3. Confirm current limit, load, and optical output path on the bench.
4. Run a manual test pulse and record the measured output.
5. Confirm that stimulation markers are exported with the recording when stimulation timing is part of the analysis.

## Metadata

Record the opto-module PCB revision, release image, stimulation channel, optical output calibration, cable or connector path, and validation file. For closed-loop studies, also record the DSP or model state that generated each stimulation event.

---

# Source file: docs/hardware/usb-board.md

# USB Board

The WILD USB-GPIO board is used for bench validation, external trigger logging, and timing integration with behavioral equipment. It provides a PC-connected GPIO path that can be used alongside WILD BLE control and logger-side digital inputs.

USB-GPIO board with IO0 to IO3 and USB interface labels

## Interface

The board exposes four external I/O channels, labeled `IO0` to `IO3`, and a USB connection to the host PC. The USB path is useful for recording external events at the PC, generating TTL outputs for external equipment, and validating synchronization behavior before animal recordings.

## Fabrication Files

USB-GPIO board manufacturing files are available in [`PCB/USBboard`](https://github.com/ayalab1/Neurologger/tree/main/PCB/USBboard).

| File | Purpose |
| --- | --- |
| [`WILD_USB_2026-06-18.zip`](https://github.com/ayalab1/Neurologger/blob/main/PCB/USBboard/WILD_USB_2026-06-18.zip) | Gerber package for PCB fabrication. |
| [`WILD_USB.xlsx`](https://github.com/ayalab1/Neurologger/blob/main/PCB/USBboard/WILD_USB.xlsx) | BOM workbook for assembly review. |
| [`WILD_USB.csv`](https://github.com/ayalab1/Neurologger/blob/main/PCB/USBboard/WILD_USB.csv) | BOM export for manufacturer upload or quick inspection. |
| [`WILD_USB.brd`](https://github.com/ayalab1/Neurologger/blob/main/PCB/USBboard/WILD_USB.brd) and [`WILD_USB.sch`](https://github.com/ayalab1/Neurologger/blob/main/PCB/USBboard/WILD_USB.sch) | Eagle board and schematic source files. |

## Windows Host Timing

The WILD device and the Windows acquisition PC use independent clocks. Keeping those clocks aligned matters when USB-GPIO trigger timestamps are merged with WILD logger events. Windows automatic time management does not calibrate drift against WILD time, and an automatic time correction can create an abrupt shift between the PC clock and the device clock during a recording.

For best synchronization accuracy with the USB-GPIO board on Windows, disable automatic time setting and automatic time-zone changes before the recording session. Download and run `TimeCalibrator` on the acquisition computer, then use the calibration record to correct PC-to-WILD time offset and drift after export.

Keep the raw USB-GPIO log, TimeCalibrator record, and corrected timestamp table with the WILD export so the synchronization correction can be audited later.

## Supported Operations

| Operation | Direction | Use case | Timing note |
| --- | --- | --- | --- |
| TTL input logging | External equipment -> USB-GPIO -> PC | Log camera, behavior, or stimulation trigger edges at the host PC. | Host timestamps must be aligned to WILD logger time before merging with neural data. |
| TTL output control | WILD or PC command -> PC -> USB-GPIO -> external equipment | Drive external cameras, stimulation controllers, or behavior systems. | Output timing includes BLE, PC scheduling, USB transfer, and GPIO latency when WILD initiates the command. |
| Periodic sync pulses | Shared pulse to USB-GPIO and WILD digital input | Estimate offset and drift between PC timestamps and WILD logger time. | Use repeated pulses across the recording, not only a start pulse. |
| Bench validation | PC plus WILD test setup | Check wiring, edge polarity, event capture, and software logging before animal sessions. | Keep a short validation recording with raw USB log and WILD export. |

See [GPIO-through-USB Trigger Alignment](../software/data-format.md#gpio-through-usb-trigger-alignment) for timestamp correction, drift monitoring, and the difference between incoming and outgoing trigger paths.

## Recommended Use

1. Assign channel names before the session, for example `camera_trigger`, `behavior_event`, `sync_pulse`, or `stim_marker`.
2. Confirm input or output direction for each channel.
3. Run a short bench pulse train through the same path used by the experiment.
4. Save the USB-GPIO log together with the WILD export.
5. Apply post-export correction before combining PC-side trigger times with WILD neural, IMU, audio, camera, or stimulation events.

## Metadata

Record the USB-GPIO board revision, connected channels, edge polarity, host software, WILD Console version, BLE controller path, and whether the board was used for input logging, output control, or both.

---

# Source file: docs/hardware/mechanical.md

# Mechanical

Mechanical files are stored in the repository for baseplates, covers, and camera-related parts.

## Available Files

| Part | Repository path |
| --- | --- |
| Top cover | [WILD_TopCover.STL](https://github.com/ayalab1/Neurologger/blob/main/3Dprint/MouseCase/WILD_TopCover.STL) |
| Baseplate | [WILD_Baseplate.STL](https://github.com/ayalab1/Neurologger/blob/main/3Dprint/MouseCase/WILD_Baseplate.STL) |
| Camera baseplate | [WILD_Baseplate_Camera.STL](https://github.com/ayalab1/Neurologger/blob/main/3Dprint/MouseCase/WILD_Baseplate_Camera.STL) |
| Mouse-case CAD source | [Wild_Case.SLDPRT](https://github.com/ayalab1/Neurologger/blob/main/3Dprint/MouseCase/Wild_Case.SLDPRT) and [WILD_Case.f3d](https://github.com/ayalab1/Neurologger/blob/main/3Dprint/MouseCase/WILD_Case.f3d) |
| Cambridge NeuroTech probe assembly | [WILDAssemblyVertical.stp](https://github.com/ayalab1/Neurologger/blob/main/3Dprint/CambridgeNT_Probe/WILDAssemblyVertical.stp), [WILDAssemblyVertical.f3d](https://github.com/ayalab1/Neurologger/blob/main/3Dprint/CambridgeNT_Probe/WILDAssemblyVertical.f3d), and printable support parts in `3Dprint/CambridgeNT_Probe/` |

## Rendered Model Views

<div class="wild-grid two">
  <figure class="wild-image-frame">
    Rendered WILD mouse case model with baseplate and cover
    <figcaption class="wild-caption">Mouse-case render showing the baseplate and cover geometry for device protection and mounting.</figcaption>
  </figure>
  <figure class="wild-image-frame">
    Rendered vertical WILD assembly for Cambridge NeuroTech probe workflow
    <figcaption class="wild-caption">Vertical assembly render for the Cambridge NeuroTech probe workflow, useful for checking model orientation and enclosure clearance. Courtesy of Adam Lowet, UC Berkeley.</figcaption>
  </figure>
</div>

## Design Considerations

- Keep cable strain relief and connector access visible in photos.
- Document orientation of the baseplate relative to probes, stimulation leads, and camera modules.
- Include printing material, layer height, support recommendations, and post-processing steps.
- Add animal-specific mounting notes only after local approval and protocol review.

---

# Source file: docs/hardware/power.md

# Power

Power planning is central to WILD experiments because battery selection, microSD choice, recording mode, selected preview signals, stimulation, and camera use all affect runtime.

## Power Architecture

The WILD device conditions the selected battery through a converter and regulator chain before powering analog acquisition, digital control, and peripheral subsystems. Battery choice should therefore follow validated hardware-revision guidance rather than a single nominal-voltage number.

Boot, microSD writes, camera use, stimulation, and live preview can create different peak-load conditions. Validate the complete experiment mode on the bench before using a battery in an animal session.

## Measured Device Modes

Representative WILD power modes are summarized here because they directly affect battery selection and runtime planning. Report these values together with the release image, SD-card model, battery, and enabled peripherals used for the session.

<div class="wild-spec-scroll" markdown="1">

| Power (mW) | Channels | Samples/s | Mode | Weight (g) | Video | Audio | Motion sensor | Processing |
| --- | ---: | ---: | --- | ---: | --- | --- | --- | --- |
| 0.11 | 0 | 0 | Sleep | 1.48 | - | - | - | - |
| 24.42 | 8 | 4.0e4 | Ephys, IMU | 1.48 | - | - | Accelerometer, gyroscope, magnetosensor | Spectral power, TinyML |
| 194.04 | 64 | 2.6e6 | Ephys, IMU | 1.48 | - | - | Accelerometer, gyroscope, magnetosensor | Spectral power, TinyML |
| 208.67 | 64 | 2.92e6 | Ephys, IMU, audio | 1.48 | - | 160 kHz ultrasonic audio path | Accelerometer, gyroscope, magnetosensor | Spectral power, TinyML |
| 245.28 | 64 | 5.48e6 | Ephys, IMU, audio, video | 1.48 | 320 x 320 px, 16 Hz | 160 kHz ultrasonic audio path | Accelerometer, gyroscope, magnetosensor | Spectral power, TinyML |

</div>

The table is a planning reference, not a substitute for bench validation. Current draw can change with release image, recording duration, SD-card behavior, battery voltage, preview state, stimulation, and camera configuration.

## Battery

The WILD device should use a battery approved for the specific hardware revision and experiment mode. Before mounting the device, confirm that the battery can boot the device without voltage sag, start recording, and sustain the planned sensors, preview state, stimulation, or camera load.

Battery examples

The [battery selection table](https://github.com/ayalab1/Neurologger/blob/main/docs/LipoBattery_selection.csv) provides baseline capacity and runtime-planning references.

## Battery Connector

The WILD device battery input uses the JST-SH connector orientation documented in the hardware setup workflow. The connector is part of the experiment record because polarity, strain relief, and repeated mating can affect boot stability and long-session reliability.

WILD connector orientation schematic

For each hardware revision, record:

- Battery connector type and orientation.
- Battery lead polarity as assembled.
- Whether the battery lead was modified, extended, or re-terminated.
- Any strain-relief method used between the battery, enclosure, and animal-mounted device.

Before a recording session, inspect the connector shell, solder joints, and battery lead for looseness or damage. Do not infer polarity from wire color alone; confirm the assembled connector orientation against the WILD hardware revision being used.

See [Hardware Setup](../getting-started/hardware-setup.md) for the first-device connector checklist.

## First Power Check

For a newly assembled WILD device, use the USB-to-4-pin bench cable and a USB power meter before connecting a battery. The first connection should draw less than 10 mA before a release image is installed; a higher or unstable current is a stop condition for solder-bridge and connector inspection.

The DFU mode-select pin can be temporarily shorted to VCC during USB connection to expose the `STM32-DFU` device for first image installation. Use the connector schematic, keep the short temporary, and verify the pin orientation before applying power.

## Battery Charger

The charger is external to the WILD recording path. Charge batteries with a single-cell lithium-polymer charger that matches the battery chemistry, capacity, connector, and manufacturer charge-current rating. Record the charger model when reporting runtime or power stability results.

The WILD device should not be treated as a battery charger unless a specific hardware revision and release note explicitly documents charging support. For the public workflow, charge and inspect the battery before connecting it to the WILD device.

Recommended charger record:

| Item | Record |
| --- | --- |
| Charger model | Identifies the charge circuit used before the session. |
| Battery model and capacity | Links runtime to the actual energy source. |
| Charge current | Helps interpret battery heating, aging, and boot margin. |
| Connector adapter | Documents any JST-SH adapter or lead conversion used between the charger and battery. |
| Pre-session check | Confirms battery voltage, connector condition, and absence of swelling or cable damage. |

## microSD Power

The microSD card is part of the power and reliability budget. Format cards with WILD Console before recording, and validate the selected card in the same sampling and modality mode planned for the experiment.

microSD power comparison

## Runtime Reporting

Runtime depends on sampling rate, active modalities, preview state, stimulation use, microSD-card model, battery capacity, and ambient conditions. When reporting a WILD recording mode, include:

- Release image.
- SD-card model and format state.
- Battery model and capacity.
- Sampling rate and enabled modalities.
- Preview state.
- Stimulation or TinyML state, if used.
- Session environment, especially for outdoor or long-duration recordings.

---

# Source file: docs/fabrication.md

# Fabrication

Board packages support ordering, assembly, and inspection for WILD hardware revisions.

## Fabrication Files

| Board | Files |
| --- | --- |
| Datalogger | [Gerbers, drill files, assembly files](https://github.com/ayalab1/Neurologger/tree/main/PCB/Datalogger) |
| Opto module | [Gerbers, drill files, assembly files](https://github.com/ayalab1/Neurologger/tree/main/PCB/Optomodule) |
| Camera unit | [Gerbers, drill files, assembly files](https://github.com/ayalab1/Neurologger/tree/main/PCB/CameraUnit) |
| USB-GPIO board | [Gerber package, BOM, and Eagle source files](https://github.com/ayalab1/Neurologger/tree/main/PCB/USBboard) |

## USB-GPIO Board Package

The USB-GPIO board fabrication package is stored in [`PCB/USBboard`](https://github.com/ayalab1/Neurologger/tree/main/PCB/USBboard). It includes the dated Gerber package, BOM files, and Eagle board/schematic source files.

| File | Purpose |
| --- | --- |
| [`WILD_USB_2026-06-18.zip`](https://github.com/ayalab1/Neurologger/blob/main/PCB/USBboard/WILD_USB_2026-06-18.zip) | Gerber package for PCB fabrication. |
| [`WILD_USB.xlsx`](https://github.com/ayalab1/Neurologger/blob/main/PCB/USBboard/WILD_USB.xlsx) | BOM workbook for assembly review. |
| [`WILD_USB.csv`](https://github.com/ayalab1/Neurologger/blob/main/PCB/USBboard/WILD_USB.csv) | BOM export for manufacturer upload or quick inspection. |
| [`WILD_USB.brd`](https://github.com/ayalab1/Neurologger/blob/main/PCB/USBboard/WILD_USB.brd) and [`WILD_USB.sch`](https://github.com/ayalab1/Neurologger/blob/main/PCB/USBboard/WILD_USB.sch) | Eagle board and schematic source files. |

## PCB Fabrication

Use the zipped Gerber and drill files for the target WILD board revision. Upload the package to a PCB manufacturer that supports fine-pitch multilayer boards; [NextPCB](https://www.nextpcb.com/) is one option used for ordering.

Recommended fabrication parameters for the current WILD datalogger board:

| Parameter | Value |
| --- | --- |
| Board thickness | 1.0 mm |
| Layer count | 4 layers |
| Minimum drill hole | 0.15 mm |
| Trace width | 3.5 mil |
| Blind vias | Rank 1 blind vias |
| Surface finish | Engineering gold, 1 uin |

Before submitting the order, confirm that the fabrication house can accept the drill files, blind-via definition, board outline, and stackup used by the selected WILD revision.

## Assembly Order

1. Upload the board package again for PCBA quotation, including the `Assembly` folder supplied with the selected WILD board revision.
2. Upload the BOM and placement files supplied for the same WILD board revision.
3. Review unavailable or special-order parts before approving assembly.
4. Confirm with the manufacturer which parts will be machine assembled and which parts will be left for hand soldering.
5. Finish hand soldering, connector inspection, and continuity checks before first power-up.

## Special Components

Some WILD components may need advance ordering or manual handling:

| Component | Manufacturing note |
| --- | --- |
| BMX160 IMU | This part is obsolete. BMI270 is a possible 6-axis replacement candidate, but the public WILD driver path is not developed yet. Do not substitute it unless the release image explicitly supports the replacement. |
| HJ580 BLE module | Confirm availability directly with HJ-SIP. Validated builds should use the HJ580 module firmware version documented for WILD, currently firmware version 20220507. |
| Omnetics A79025 | This 64-channel probe connector has a high failure rate during standard reflow. Prefer manual soldering with an alignment fixture, then inspect alignment, solder bridges, and continuity under magnification. |

## Post-Assembly Bring-Up

Prepare a bench cable before applying power to a newly assembled WILD device.

1. Solder the WILD 4-pin JST-SH 1.0 mm cable according to the connector illustration in [Hardware Setup](getting-started/hardware-setup.md).
2. Pre-crimped JST-SH 1.0 mm wire leads or equivalent lab-qualified leads can be used for cable preparation after verifying polarity and pin order.
3. Build a 4-pin USB power/programming cable by soldering the JST-SH lead to a USB-A connector breakout or equivalent bench-supply adapter. Keep the cable labeled and reuse it only after continuity checks.
4. Place a USB power meter between the PC or USB supply and the 4-pin cable.
5. Connect the WILD device for the first time and check the current before programming. Current below 10 mA is the expected first-pass check for no obvious short circuit; disconnect immediately if the current is higher than expected or unstable.
6. Momentarily short the DFU mode-select pin to VCC with metal tweezers while connecting USB, using the connector schematic to avoid shorting the wrong pins.
7. Confirm that the PC detects an `STM32-DFU` device. If the driver is missing, install the ST DFU driver package from [STSW-STM32080](https://www.st.com/en/development-tools/stsw-stm32080.html).
8. Open WILD Console, go to the **Advanced** tab, and use the packed DFU update pipeline to select the latest validated `.hex` release image.
9. After the first DFU installation succeeds, use the documented microSD release-image update path for later upgrades when the release notes support it.

## Inspection Checks

- Confirm top and bottom orientation against the board files.
- Inspect the microSD socket, battery connector, BLE UART pins, sensor connectors, stimulation output path, and probe connector before power-up.
- Check for solder bridges around fine-pitch parts and high-density connectors.
- Keep the PCB revision, manufacturer, assembly date, special part substitutions, and release-image filename with the experiment metadata.
- Match each board revision to a compatible release image before recording.

---

# Source file: docs/software/index.md

# Software

Software documentation covers how to connect to the WILD device, configure recordings in WILD Console, export data from the device microSD card, and process recordings for analysis.

## Software Components

<div class="wild-grid wild-nav-grid">
  <a class="wild-card wild-card-link wild-card-compact" href="acquisition/">
    <div>
    <h3>WILD Console</h3>
      <p>Connect and export</p>
    </div>
  </a>
  <a class="wild-card wild-card-link wild-card-compact" href="artificial-intelligence/">
    <div>
      <h3>Embedded AI</h3>
      <p>Validated models</p>
    </div>
  </a>
  <a class="wild-card wild-card-link wild-card-compact" href="api-cli/">
    <div>
      <h3>Scripts</h3>
      <p>Batch tools</p>
    </div>
  </a>
  <a class="wild-card wild-card-link wild-card-compact" href="../analysis/">
    <div>
      <h3>Analysis</h3>
      <p>MATLAB and Python</p>
    </div>
  </a>
</div>

## Install

Download WILD Console from the [latest GitHub release](https://github.com/ayalab1/Neurologger/releases/latest). The link always opens the newest public WILD release.

## Public Workflow Boundary

The current public software path is:

1. Connect and record with WILD Console.
2. Export from the device microSD card.
3. Run documented MATLAB or Python post-processing.

The public documentation does not treat BLE as a continuous high-bandwidth acquisition path, and it does not promise a stable general-purpose SDK yet.

## Wireless Control

WILD Console remains the stable public control and export workflow for BLE discovery, connection, synchronization support, status checks, selected preview, low-bandwidth commands, and SD-card export.

Full-resolution WILD recordings remain local to the device microSD card and are exported after the session.

## Requirements

- Windows 10 or later.
- .NET Framework 4.8 for the current GUI.
- Bluetooth 4.0 or later.
- Administrator privileges for some SD-formatting workflows.

## Optional Runtime Files

- `dll_upfirdn.dll` for resampling.
- WILD BLE backend DLL for BLE support in older installer layouts.
- `ffmpeg.exe` for some camera processing workflows.

---

# Source file: docs/software/acquisition.md

# Acquisition

The acquisition workflow starts by connecting to a WILD device in WILD Console and ends with exported recording folders from the device microSD card.

The WILD device records high-bandwidth neural and multimodal data locally. BLE is used for discovery, synchronization support, configuration, status, selected preview, and control commands rather than continuous full-bandwidth data streaming.

WILD Console is the stable public control path today. Full-resolution recordings remain stored on the device microSD card.

## Recording Prerequisites

Before acquisition, prepare the Windows host clock for any timing-sensitive session. Disable automatic time setting and automatic time-zone changes, run `TimeCalibrator`, and keep the calibration record with the exported dataset. This is required when USB-GPIO logs, behavior timestamps, camera triggers, stimulation markers, or multi-device sessions will be aligned to WILD logger time.

The WILD device and PC use independent clocks. Windows automatic time management does not calibrate drift against the WILD clock and can create an abrupt PC-clock shift during the session if an automatic correction occurs.

## Wireless Connection Model

The WILD device can be connected for discovery, synchronization support, parameter review, selected preview, and command delivery. After setup and timing coordination, local recording does not depend on continuous full-bandwidth wireless streaming because the device writes the full dataset to microSD.

For multi-device sessions, keep continuous BLE connected only for devices that need live preview or online commands. Devices that only need local logging can be configured and synchronized first, then managed with the planned start, stop, external I/O, and export workflow.

## Routine Operation Map

Most first-session work uses four button groups:

| Stage | Main UI area | Primary click |
| --- | --- | --- |
| Discover and connect | Online tab, Device List | <span class="wild-button-label">Rescan</span>, select the WILD device, then <span class="wild-button-label primary">Connect</span> |
| Start recording | Online tab, recording controls | <span class="wild-button-label primary">Recording Start</span> |
| Stop recording | Online tab, recording controls | <span class="wild-button-label">Recording Stop</span> |
| Export data | Offline tab, File panel | <span class="wild-button-label primary">Save to Disk</span> |

Closed-loop settings, camera controls, stimulation parameters, GPIO options, and advanced panels are optional experiment-specific controls. Configure them after the basic connect-record-export path is working.

WILD Console runtime screenshot of the offline export workflow

## Typical Session

1. Start WILD Console.
2. Complete Windows clock preparation if the session uses PC-side timestamps or external timing alignment.
3. Scan for the WILD device.
4. Connect over BLE.
5. Read current parameters and change experiment-specific settings only when needed.
6. Configure sampling, closed-loop, camera, stimulation, and GPIO options as needed.
7. Start local recording.
8. Monitor selected preview and state signals.
9. Stop recording.
10. Export data from the SD card.
11. Check duration, file size, representative channels, and sync markers before treating the session as complete.
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

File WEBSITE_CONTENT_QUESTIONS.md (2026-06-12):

# WILD Website Content Questions

This file collects the parts of the current documentation site that need your confirmation or more project-specific detail. Fill in answers directly under each item. I will use those answers to replace draft wording, add exact specs, and make the public site more credible.

This file is intentionally outside `docs/`, so it is not part of the published MkDocs website.

## Priority 1: Public Launch Blockers

### 1. Project naming and positioning

Current site uses:

- Public name: `WILD`
- Expansion: `Wireless Intelligent Logger`
- Repository/project URL: `zifangzhao/Neurologger`
- Site title: `WILD: Open-source Wireless Neurotechnology for Naturalistic Neuroscience`

Questions:

- Should the public-facing name always be `WILD` across device variants, software, firmware, and documentation?
- Should `Neurologger` appear only as the legacy repository name, or should the repository be renamed later?
- Should the headline keep "Open-source Wireless Neurotechnology" or use a narrower phrase such as "Wireless Neural Logger"?

Answer:

### 2. Hardware revision and supported device variants

The docs currently describe the platform generally, without exact revision names.

Questions:

- Which hardware revision should be documented first?
- What are the exact WILD hardware variant names or revision names we should use publicly?
- What are the exact channel counts and supported recording modes for each WILD variant?
- Which features are stable today, and which should be labeled experimental?

Answer:

### 3. Core specifications

The public site needs a compact specs table.

Questions:

- Device mass:
- Device dimensions:
- Battery range:
- Typical battery life by mode:
- Neural channel count:
- Sampling rates:
- ADC resolution:
- Storage type and recommended SD cards:
- BLE role and supported operating systems:
- IMU model and sampling modes:
- Audio/USV bandwidth:
- Camera support details:
- Stimulation output type and limits:

Answer:

### 4. Device images and figure policy

Your requirement is clear: no AI-generated device photographs or device illustrations.

Questions:

- Can we publicly use all current `docs/images/WIrelessEphys_*.jpg` images?
- Which images are real device photos?
- Which images are schematic, CAD, PCB, or hand-authored diagrams?
- Are there images that should be removed before public hosting?
- Should image captions include hardware revision, date, or source file?

Answer:

### 5. Publications and citation

The current site has a placeholder repository citation.

Questions:

- Is there a preferred author list for the repository citation?
- Is there a platform manuscript, preprint, protocol, conference abstract, or dataset DOI to cite?
- Should the citation year be 2026, or another year?
- Should the site include BibTeX, APA, and/or Nature-style citation text?

Answer:
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

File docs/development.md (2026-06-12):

# Development & Contributing

## Repo Structure

- `Software/` - WILD acquisition installers and release assets.
- `Code/` - WILD analysis and utility scripts.
- `Firmware/` - WILD firmware images and reference sources.
- `PCB/` - WILD PCB fabrication and assembly assets.
- `3Dprint/` - WILD mechanical files.
- `docs/` - documentation site.

## Contributing

We welcome issues and pull requests.

1. Fork the repo.
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

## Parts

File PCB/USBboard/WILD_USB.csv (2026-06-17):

Qty | Value | Device | Package | Parts | Description | MF | MPN | OC_FARNELL | OC_NEWARK | POPULARITY | SPICEMODEL | SPICEPREFIX
5 | 100 | RR1206 | R1206 | R1, R2, R3, R4, R7 | RESISTOR, European symbol |  |  |  |  |  | NONE | R
7 | 1u | CC1206 | C1206 | C3, C4, C6, C8, C9, C10, C13 | CAPACITOR, European symbol |  |  |  |  |  | NONE | C
1 | 2*5P 2.54mm 双排母 母座 | 2.54MM_2X5 | 2.54MM_2X5 | J3
2 | 20p | CC1206 | C1206 | C1, C5 | CAPACITOR, European symbol |  |  |  |  |  | NONE | C
1 | 22-23-2021 | 22-23-2021 | 22-23-2021 | X6 | .100 (2.54mm) Center Header - 2 Pin" | MOLEX | 22-23-2021 | 1462926 | 25C3832 | 40
4 | 22u | CC1206 | C1206 | C2, C7, C11, C12 | CAPACITOR, European symbol |  |  |  |  |  | NONE | C
1 | 24MHz | CRYSTALSMD | HC49UP | Y1 | Crystals
3 | 5k | RR1206 | R1206 | R5, R6, R8 | RESISTOR, European symbol |  |  |  |  |  | NONE | R
1 | A127799-ND | ATX_24P | ATX_24P | J4
1 | ADP3338AKCZ-3.3 | AMS1117 | SOT223 | U4
4 | BNC_8MM | BNC_8MM | BNC_V_8MM | X2, X3, X4, X5
3 | Blue | LED1206 | CHIPLED_1206 | LED1, LED2, LED3 | LED
1 | DC_POWER_JACK-PJ-102AH | DC_POWER_JACK-PJ-102AH | PJ-102AH | J6 | DC Power Jack
1 | HJ580 | HJ580 | HJ580 | U2
1 | HJ_185IMHQFN | HJ_185IMHQFN | HJ_185IMH | U3
6 | HY2.0 8P SMD卧贴插座 | JST_8PIN | JSTPH8 | CN_IN1, CN_IN2, CN_IN3, CN_IN4, CN_LCD, CN_OUT1 | JST 8-Pin Right-Angle Connector
1 | J7 | MICRO-USB-ZX62R-B-5P | ZX62R-B-5P | J7 | Hirose Micro USB Connector
8 | MMSZ4684T1GOSCT-ND | DIODE_ZENER_SOD-123 | SOD-123 | D1, D2, D3, D4, D5, D6, D7, D8 | Zener diode
1 | STM32F413CHU6 | STM32F411_QFN48 | UFQFPN48 | U1
1 | Sub-GHz | SYN115 | SYN115 | J1
2 | TESTPOINT_SMALL | TESTPOINT_SMALL | TESTPOINT_SMALL | CLK, DIO | PCB Test Point
1 | WM5525-ND | BU-SMA-H | BU-SMA-H | X1 | FEMALE SMA CONNECTOR |  |  | unknown | unknown | 4
1 | Wifi | WIRELESS-WIFI-ESP-01 | WIRELESS-WIFI-ESP-01 | J2 | Wireless Wi-Fi ESP-01 Module based on ESP8266 chip
1 | nc | AMS1117 | SOT223 | U5
1 | nc | JUMPER2 | JUMPER2 | J5
1 | nc | RR1206 | R1206 | 5V_BYP | RESISTOR, European symbol |  |  |  |  |  | NONE | R

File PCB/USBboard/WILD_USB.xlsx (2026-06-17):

产品分类 | 型号/参数 | 封装 | 品牌 | 单机用量 | 位号 |  | 总量 | 10
连接器 | 2P 2.54mm 母座 | XH2.54 |  | 1 | X6
连接器 | 10P 2.54mm 母座 | SFH11 | Sullins | 1 | J3
IC | LD1117S33TR | SOT223 | ST | 1 | U4
IC | LD1117S50TR | SOT223 | ST | 1 | U5
BNC母座 |  | B04-BJPT4-41BS00 |  | 4 | X2, X3, X4, X5
SMA母座 | BU-SMA-H |  |  | 1 | X1
贴片电容 | 1uF 10% 25V | 1206 | samsung | 7 | C3, C4, C6, C8, C9, C10, C13
贴片电容 | 20pF 10% 25V | 1206 | samsung | 2 | C1,C5
贴片电容 | 22uF 10% 25V | 1206 | samsung | 4 | C2, C7, C11, C12
晶振 | 24MHz | HC49UP | Abracon | 1 | Y1
齐纳二极管 | MMSZ4684T1GOSCT-ND | SOD-323 | ON Semiconductor | 8 | D1, D2, D3, D4, D5, D6, D7, D8
蓝牙模块 | HJ580 |  |  | 1 | U2 | 软件版本号 V3.1
8pin连接器 | JST 8-Pin Right-Angle Connector | HY2.0 8P | JST | 6 | CN_IN1, CN_IN2, CN_IN3, CN_IN4, CN_LCD, CN_OUT1
贴片发光二极管 | 蓝色1206 | 1206 |  | 3 | LED1, LED2, LED3
贴片电阻 | 100R 10% | 1206 | samsung | 5 | R1, R2, R3, R4, R7
贴片电阻 | 5k 10% | 1206 | samsung | 3 | R5, R6, R8
IC | STM32F413CHU6 | UFQFPN48 | STM | 1 | U1
连接器 | MICRO-USB-ZX62R-B-5P | microUSB侧贴 | Hirose | 1 | J7
 | 特殊物料，自行采购

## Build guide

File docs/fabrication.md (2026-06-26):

# Fabrication

Board packages support ordering, assembly, and inspection for WILD hardware revisions.

For day-to-day bench work after PCBA delivery, use the detailed [WILD soldering and rework SOP](fabrication/soldering-rework.md). It covers microscope assembly, double-sided fixturing, hot-air rework, STM32 QFN replacement, Intan BGA reballing, and Omnetics connector hand soldering.

## Fabrication Files

| Board | Files |
| --- | --- |
| Datalogger | [Gerbers, drill files, assembly files](https://github.com/ayalab1/Neurologger/tree/main/PCB/Datalogger) |
| Opto module | [Gerbers, drill files, assembly files](https://github.com/ayalab1/Neurologger/tree/main/PCB/Optomodule) |
| Camera unit | [Gerbers, drill files, assembly files](https://github.com/ayalab1/Neurologger/tree/main/PCB/CameraUnit) |
| USB-GPIO board | [Gerber package, BOM, and Eagle source files](https://github.com/ayalab1/Neurologger/tree/main/PCB/USBboard) |

## USB-GPIO Board Package

The USB-GPIO board fabrication package is stored in [`PCB/USBboard`](https://github.com/ayalab1/Neurologger/tree/main/PCB/USBboard). It includes the dated Gerber package, BOM files, and Eagle board/schematic source files.

| File | Purpose |
| --- | --- |
| [`WILD_USB_2026-06-18.zip`](https://github.com/ayalab1/Neurologger/blob/main/PCB/USBboard/WILD_USB_2026-06-18.zip) | Gerber package for PCB fabrication. |
| [`WILD_USB.xlsx`](https://github.com/ayalab1/Neurologger/blob/main/PCB/USBboard/WILD_USB.xlsx) | BOM workbook for assembly review. |
| [`WILD_USB.csv`](https://github.com/ayalab1/Neurologger/blob/main/PCB/USBboard/WILD_USB.csv) | BOM export for manufacturer upload or quick inspection. |
| [`WILD_USB.brd`](https://github.com/ayalab1/Neurologger/blob/main/PCB/USBboard/WILD_USB.brd) and [`WILD_USB.sch`](https://github.com/ayalab1/Neurologger/blob/main/PCB/USBboard/WILD_USB.sch) | Eagle board and schematic source files. |

## PCB Fabrication

Use the zipped Gerber and drill files for the target WILD board revision. Upload the package to a PCB manufacturer that supports fine-pitch multilayer boards; [NextPCB](https://www.nextpcb.com/) is one option used for ordering.

Recommended fabrication parameters for the current WILD datalogger board:

| Parameter | Value |
| --- | --- |
| Board thickness | 1.0 mm |
| Layer count | 4 layers |
| Minimum drill hole | 0.15 mm |
| Trace width | 3.5 mil |
| Blind vias | Rank 1 blind vias |
| Surface finish | Engineering gold, 1 uin |

Before submitting the order, confirm that the fabrication house can accept the drill files, blind-via definition, board outline, and stackup used by the selected WILD revision.

## Assembly Order

1. Upload the board package again for PCBA quotation, including the `Assembly` folder supplied with the selected WILD board revision.
2. Upload the BOM and placement files supplied for the same WILD board revision.
3. Review unavailable or special-order parts before approving assembly.
4. Confirm with the manufacturer which parts will be machine assembled and which parts will be left for hand soldering.
5. Finish hand soldering, connector inspection, and continuity checks before first power-up.

## Special Components

Some WILD components may need advance ordering or manual handling:

| Component | Manufacturing note |
| --- | --- |
| BMX160 IMU | This part is obsolete. BMI270 is a possible 6-axis replacement candidate, but the public WILD driver path is not developed yet. Do not substitute it unless the release image explicitly supports the replacement. |
| HJ580 BLE module | Confirm availability directly with HJ-SIP. Validated builds should use the HJ580 module firmware version documented for WILD, currently firmware version 20220507. |
| Omnetics A79025 | This high-density Omnetics probe connector has a high failure rate during standard reflow. Prefer manual soldering with an alignment fixture, then inspect alignment, solder bridges, and continuity under magnification. The detailed connector workflow is documented in the [WILD soldering and rework SOP](fabrication/soldering-rework.md). |

## Post-Assembly Bring-Up

Prepare a bench cable before applying power to a newly assembled WILD device.

1. Solder the WILD 4-pin JST-SH 1.0 mm cable according to the connector illustration in [Hardware Setup](getting-started/hardware-setup.md).
2. Pre-crimped JST-SH 1.0 mm wire leads or equivalent qualified leads can be used for cable preparation after verifying polarity and pin order.
3. Build a 4-pin USB power/programming cable by soldering the JST-SH lead to a USB-A connector breakout or equivalent bench-supply adapter. Keep the cable labeled and reuse it only after continuity checks.
4. Place a USB power meter between the PC or USB supply and the 4-pin cable.
5. Connect the WILD device for the first time and check the current before programming. Current below 10 mA is the expected first-pass check for no obvious short circuit; disconnect immediately if the current is higher than expected or unstable.
6. Momentarily short the DFU mode-select pin to VCC with metal tweezers while connecting USB, using the connector schematic to avoid shorting the wrong pins.
7. Confirm that the PC detects an `STM32-DFU` device. If the driver is missing, install the ST DFU driver package from [STSW-STM32080](https://www.st.com/en/development-tools/stsw-stm32080.html).
8. Open WILD Console, go to the **Advanced** tab, and use the packed DFU update pipeline to select the latest validated `.hex` release image.
9. After the first DFU installation succeeds, use the documented microSD release-image update path for later upgrades when the release notes support it.

## Inspection Checks

- Confirm top and bottom orientation against the board files.
- Inspect the microSD socket, battery connector, BLE UART pins, sensor connectors, stimulation output path, and probe connector before power-up.
- Check for solder bridges around fine-pitch parts and high-density connectors.
- Keep the PCB revision, manufacturer, assembly date, special part substitutions, and release-image filename with the experiment metadata.
- Match each board revision to a compatible release image before recording.

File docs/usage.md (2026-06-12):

# Usage Guide

## Pre-recording Preparations

1. Prepare or recharge the battery. WILD includes a DC/DC buck-boost converter and accepts a wide input range from 2 V to 4.5 V. The battery must supply the minimum power required by the selected recording mode and should support more than 30 mW peak power during boot.

   Battery

   [Battery selection table](https://github.com/zifangzhao/Neurologger/tree/main/docs/LipoBattery_selection.csv)

2. Format the microSD card using WILD_console. Make sure WILD_console has administrator privileges. Some SanDisk microSD cards may not be supported; Samsung EVO series or Lexar cards are recommended. Avoid unnecessarily high-speed cards because they can consume more power.

   SD card

3. Insert the microSD card into WILD.

4. Connect the battery. The device will start booting. A blue LED turns on when the device starts correctly, then turns off when the device enters low-power mode. If a firmware image is loaded on the microSD card, the device checks the image and starts upgrading. The LED blinks during upgrade, which takes about 10 seconds depending on image size.

   IO configuration

## Connecting

1. Launch `WILD_console.exe`.
2. Select the device from the port dropdown after BLE scan.
3. Connect and wait for synchronization. A number at the bottom of the panel should increase when communication is working.

If connection succeeds but synchronization does not start, or the TX number does not increase, check the microSD card.

## Recording

1. Configure closed-loop functions in the closed-loop panel.
2. Configure recording speed with the custom speed dropdown.
3. For multi-device recording, use **Wait for start** to coordinate multiple WILD_console instances. Bluetooth start jitter is expected to be below 50 ms, while the recording start timestamp is recorded from the calibrated high-precision clock.
4. Click **Recording Start**. Data streaming starts after about 1 second.
5. Click **Recording Stop** when the experiment is finished. If the battery dies during recording, completed recording files should remain available on the microSD card.

## Real-time Display

- Preview streaming is enabled by default when recording starts.
- Preview channels can be selected through **Display Channel**.
- Auxiliary signals from IMU and DSP can be selected through **Display Auxiliary**.
- Preview can be turned off to save power and host BLE bandwidth.
- Internal state display shows closed-loop detection, stimulation trigger, DSP states, and TinyML model states.
- Display length options include 1 s, 2 s, 5 s, and 10 s.
- Gain options range from 10 uV to 5 mV.
- Threshold overlays are available during closed-loop operation when the corresponding DSP channels are selected.

Real-time control

## Data Download

1. Insert the microSD card into the host computer.
2. Click **Save to Disk** and select the target folder.
3. Data will be organized by recording ID and recording start timestamp.

Offline interface

## Post Processing

Processing scripts are available in [Code](https://github.com/zifangzhao/Neurologger/tree/main/Code).

1. Run `WILD_PreProcess.m` to generate corrected headers and `time.dat`. This also generates FMAToolbox-style event files from digital input signals.
2. For recordings with camera data, decode `misc.dat` with `WILD_VideoDecodewAudio.py`.
3. For IMU sensor fusion, run `WILD_processIMU.m`.

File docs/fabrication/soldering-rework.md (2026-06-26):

# WILD Soldering and Rework SOP

This SOP is for operators assembling or repairing the double-sided WILD datalogger PCB. It covers microscope work, hot-air rework, reflow-oven use, STM32 UFQFPN48 replacement, Intan RHD2164 BGA bake/reball/reinstall, and Omnetics A79025 connector microsoldering.

Use this document together with the WILD datalogger assembly files:

- [WILD datalogger assembly folder](https://github.com/ayalab1/Neurologger/tree/main/PCB/Datalogger/Assembly)
- [XE64_HDI part list](https://github.com/ayalab1/Neurologger/blob/main/PCB/Datalogger/Assembly/XE64_HDI.txt)
- [PnP front](https://github.com/ayalab1/Neurologger/blob/main/PCB/Datalogger/Assembly/PnP_XE64_HDI_front.txt)
- [PnP back](https://github.com/ayalab1/Neurologger/blob/main/PCB/Datalogger/Assembly/PnP_XE64_HDI_back.txt)

## Scope

This SOP is written for the current WILD datalogger assembly, a dense double-sided HDI board with parts on both sides.

It is intended as a public process guide rather than a fixed recipe. Validate temperatures, dwell times, alloys, and moisture-control steps against the active component datasheets, solder materials, and rework equipment before using the procedure on a device.

| Target | WILD ref | Package | Side | Notes |
| --- | --- | --- | --- | --- |
| Main MCU | `U$6` | STM32F411 `UFQFPN48` | Back | 7 x 7 mm, 0.5 mm pitch, exposed pad |
| Neural frontend | `U$1` | Intan `RHD2164` `BGA104_9X7` | Front | 9 x 7 mm, 104-pin, 0.5 mm pitch |
| Probe connector | `S1`, `S3` | Omnetics `A79025` | Front and back | Manual soldering only in this SOP |
| Board style | whole board | double-sided dense PCB | Both | 0201/0402 passives, nearby heat-sensitive plastics |

## Non-Negotiable Rules

1. Work under ESD protection, with microscope, fume extraction, and a rigid PCB support fixture.
2. Do not use hot air on a populated WILD board without controlling airflow, dwell time, and shielding of nearby parts.
3. Do not rely on station dial numbers. Use measured board/package temperature during initial setup.
4. Do not pry QFN, BGA, or Omnetics parts off the board. Lift only after full reflow.
5. Do not scrub BGA pads with dry braid or force. Wicking is capillary action, not abrasion.
6. For Omnetics work, minimize housing temperature and dwell. The connector material can be damaged near its approximate `220 C` thermal limit unless the supplier documentation for the exact part revision says otherwise.
7. For Intan reballing, use a matching laser-cut stencil, a stable alignment fixture, and preformed solder balls that match the intended alloy.
8. If alloy history is unknown, stop and document it before rework. Do not mix alloys casually on the target board.
9. If a chip pad, board pad, or connector contact is visibly damaged, stop and escalate before continuing.

## Required Bench Setup

- Stereo microscope with enough clearance for hot air and tweezers
- ESD mat, wrist strap, ESD-safe chip tray, and grounded tools
- Hot-air station with small nozzles and controllable airflow
- Fine soldering iron with small chisel or hoof tips
- Fine tweezers, vacuum pickup, Kapton tape, and metal heat shields
- Flux: one tacky gel flux for rework and one liquid flux for touch-up/drag soldering
- Fresh solder braid in small widths; replace braid often during BGA cleanup
- Thin solder wire for hand work; choose an alloy that matches the intended process and rework plan
- Solvent and lint-free swabs for cleaning
- Continuity meter and bench supply with current limit

## WILD Board Fixturing

The WILD datalogger is not a flat board once one side is populated. Support strategy matters.

- Use a fixture with relief pockets for already-installed opposite-side parts.
- Never press the board flat onto a bench once either Omnetics connector is installed.
- Support the board close to the work area so local pressure does not flex the HDI stackup.
- During front-side Intan work, protect the nearby microSD socket and camera-side hardware from direct airflow.
- During back-side STM32 work, protect the HJ580 module and nearby 0201 parts from airflow and accidental bumping.

## Standard Build Order for New Boards

Recommended sequence for the current WILD datalogger:

1. Inspect bare boards for warpage, pad damage, solder-mask defects, and contamination.
2. Verify the exact board revision and pull the matching assembly files before placing parts.
3. Confirm dry-pack/MSL status for moisture-sensitive ICs. If the original packaging state is unknown, follow the component supplier guidance and current JEDEC moisture-control rules before heating the part.
4. First oven pass: assemble the back side first, centered around the STM32 side (`U$6`, HJ580, passives, regulators).
5. Inspect, clean bridges, and confirm the first side is mechanically stable.
6. Second oven pass: assemble the front side with the Intan BGA (`U$1`), microSD, camera-side components, and the remaining low-profile parts.
7. Leave both Omnetics connectors (`S1`, `S3`) out of the oven process unless a separate validated profile exists. Install them by hand after both oven passes.
8. Perform hand rework and final inspection only after both reflow passes are complete.

### Reflow Oven Guidance

- Use the solder paste vendor's profile as the starting point, not a generic toaster-oven recipe.
- Record the first successful profile with thermocouples on a setup board or process coupon.
- For WILD, confirm that the second pass does not shift first-pass small parts or remelt unsupported heavy parts.
- Keep time above liquidus and peak temperature as low as the paste vendor allows while still producing full wetting.
- If a board contains Omnetics connectors, do not send it back through an unvalidated full-board reflow cycle.

## General Local Rework Method

Use this sequence for all local hot-air work on populated boards:

1. Photograph the area before touching it.
2. Fixture the board so it cannot sag or rock.
3. Warm the area gradually before pushing to reflow temperature. The goal is to reduce thermal shock and avoid excessive top-side dwell.
4. Shield nearby plastics and small passives with foil or a dedicated heat shield.
5. Apply flux before heating.
6. Use the smallest nozzle that still heats the full package evenly.
7. Keep airflow low enough that adjacent 0201 parts do not move.
8. Remove the part only when it lifts freely.
9. Clean and inspect pads before placing the replacement.
10. After rework, clean residue, inspect under microscope, then do electrical checks before power.

## STM32 UFQFPN48 SOP

The WILD datalogger uses `U$6`, a 48-lead `UFQFPN48` STM32 package on the back side of the board.

### Removal

1. Support the front side so no installed connector or socket is carrying load.
2. Start with a gentle warm-up pass over the package area.
3. Add flux around all four sides of the QFN and around the exposed-pad area through thermal relief where accessible.
4. Heat evenly with hot air until the package releases without force.
5. Lift vertically. Do not lever under an edge with tweezers.

### Pad Cleanup

1. Flood pads with flux.
2. Wick the perimeter pads flat with a small braid and minimal pressure.
3. Wick the exposed pad until it is flat and bright, but do not leave a large solder mound.
4. Clean, then inspect for lifted pads, solder-mask damage, or bridged vias in the thermal region.

### Replacement

1. Apply a controlled amount of paste or solder to the perimeter pads.
2. Keep solder volume on the exposed pad low. Too much solder on the center pad will float the package and open the perimeter leads.
3. Place the new STM32 with correct `Pin 1` orientation under microscope.
4. Reflow with controlled local top heat until the package settles and self-centers.
5. Touch up only if needed. If drag soldering is required, use liquid flux and minimal solder.

### Acceptance

- Package sits flat with no visible rock
- All four sides are centered and evenly wetted
- No bridges between side pads
- Exposed pad is soldered to ground as required by the package guidance
- No short from rail to ground before power-up

### References

- [QFN hot-air rework tutorial](https://www.youtube.com/watch?v=kmX_oLPy08o)

## Omnetics A79025 Microsoldering SOP

The WILD board uses Omnetics `A79025` connectors on both sides (`S1` on the front, `S3` on the back). This is the highest-risk manual connector step on the board.

### Process Rules

- Treat the connector as a hand-soldered part, not a standard full-oven part.
- Keep connector-body temperature well below its approximate `220 C` housing limit.
- Use a fixture or alignment support so the connector mouth stays parallel to the board edge.
- Use an alloy and flux system compatible with the connector plating, board finish, and the rest of the assembly.

### Placement and Tacking

1. Inspect the footprint and confirm front/back orientation from the placement file before opening the connector tray.
2. Lightly flux the footprint.
3. Pre-tin one small anchor point or one corner pad only.
4. Place the connector under microscope and tack one end.
5. Re-check alignment against the footprint and board edge.
6. Tack the opposite end only after the first tack is confirmed correct.

### Soldering

1. Use a temperature-controlled iron and work in short dwell intervals so the connector body does not overheat.
2. Work with a fine tip and very small solder additions.
3. Solder from one side toward the other with fresh flux.
4. If drag soldering is used, keep the solder bead very small and clean the tip often.
5. Let the connector cool between rows if the body is heating up.
6. Clean bridges immediately while the connector is still firmly supported.

### Removal/Rework

- Do not pull on the connector shell.
- Reflow the full row or side evenly before lifting.
- If the body discolors, softens, or shifts, scrap the connector and inspect the PCB before trying again.

### Acceptance

- Connector mouth is parallel to the board edge and sits flat
- No visible bridges at the contact row
- No pad lifting at the ends
- Continuity passes on all channels that should connect
- No shorts between adjacent high-density contacts

### References

- [Omnetics FAQ](https://www.omnetics.com/about/faqs/)
- [Omnetics engineering support](https://www.omnetics.com/contact/engineering-support/)
- [Omnetics catalogs and part search](https://www.omnetics.com/resources/catalogs/)

## Intan RHD2164 BGA SOP

This is the most critical rework on the WILD board. The WILD datalogger uses `U$1`, an Intan `RHD2164` in a `104-pin`, `9 x 7 mm`, `0.5 mm pitch` BGA package.

### When to Reball Instead of Replace

Reball only if all of the following are true:

- The package body is flat and uncracked
- No corner is chipped
- No pad is visibly missing after cleanup
- The board failure points to a solder-joint problem, not confirmed silicon damage

If any of those checks fail, replace the chip instead of reballing it.

### Dry Handling and Bake

- Treat removed or previously opened Intan BGAs as moisture-sensitive.
- If the original bag label and floor-life state are available, follow that JEDEC/package handling information.
- If the original dry-pack state is unknown, follow the supplier handling guidance and current JEDEC moisture-control rules before reballing or reinstalling. Do not guess a high-temperature bake at the bench.
- After dry-out, keep the part in a dry box or sealed dry pack until the reball job starts.

### Board-Side Removal

1. Protect the nearby microSD socket and adjacent components.
2. Warm the area gradually before pushing to reflow temperature.
3. Apply flux around the BGA perimeter.
4. Heat evenly with low-to-moderate airflow until the package releases.
5. Lift vertically with vacuum pickup. Do not slide the chip sideways across softened pads.

### Board Pad Cleanup

1. Flood with flux.
2. Add a small amount of fresh solder only if needed to improve wetting.
3. Wick pads flat with light pressure.
4. Clean until the full site is flat, bright, and level.
5. Inspect every pad field edge for lifted mask or torn pads.

### Chip Underside Cleanup

This is the step most likely to damage a reusable BGA package.

1. Place the removed chip underside-up in a stable ESD fixture.
2. Preheat gently so the braid is not doing all the thermal work.
3. Apply flux across one small area only.
4. Use fresh braid and a flat tip. Touch, let the solder wick, then lift.
5. Move in short passes. Replace braid often.
6. If residue remains, re-flux and repeat. Do not push harder.
7. If the old solder is stubborn, add a very small amount of fresh compatible solder first, then wick again.
8. Never scrape pads with a blade, fiberglass pen, or dry braid.

The goal is to leave a clean, flat pad array without gouging the package metallization.

### Reballing With a Laser Stencil and Cold Alignment Tool

1. Clean the underside and verify the pad field is complete before loading the fixture.
2. Load the part into the cold alignment tool.
3. Apply only a very thin film of tacky flux. Excess flux causes ball float and bridges.
4. Align the laser stencil by the outer pad rows and corners under microscope.
5. Roll or brush the preformed solder balls into the stencil until every aperture is filled.
6. Remove stray balls before heating.
7. Reflow just long enough for each ball to wet and form. Do not over-dwell.
8. Cool without movement.
9. Inspect for missing balls, bridges, collapsed balls, and row skew before taking the chip out of the fixture.

### Reinstalling the Reballed Intan

1. Confirm the board site is flat and clean.
2. Apply a thin flux film to the board site.
3. Align the chip carefully to the pad grid under microscope.
4. Use controlled local top heat until the BGA self-centers and settles.
5. Do not press on the package while the solder is liquid.
6. Let the board cool undisturbed before cleaning.

### Acceptance

- Outer rows appear evenly collapsed and centered
- Package edges are parallel to the footprint
- No immediate VDD-to-GND short
- No obvious SPI-line shorts to neighbors
- If X-ray is available, use it on initial Intan rework runs and on any board with uncertain alignment

### Stop Conditions

Stop and escalate if any of these occur:

- Board pad lift
- BGA pad loss on the chip
- Package corner crack or body warpage
- Multiple missing balls after two reball attempts
- Package will not self-center during reinstall

### References

- [Intan RHD2164 datasheet](https://intantech.com/files/Intan_RHD2164_datasheet.pdf)
- [Intan RHD2000 series datasheet](https://intantech.com/files/Intan_RHD2000_series_datasheet.pdf)
- [IPC/JEDEC J-STD-020E table of contents](https://www.ipc.org/TOC/IPC-JEDEC-J-STD-020E.pdf)
- [BGA reflow tutorial](https://www.youtube.com/watch?v=cTfuaNqfPKI)

## Final Inspection and Power-Up

Before first power after any major rework:

1. Inspect the reworked area at full microscope zoom.
2. Measure resistance from each main rail to ground and compare with a reference board when one is available.
3. Confirm there is no obvious bridge at the STM32, Intan, or Omnetics site.
4. Clean flux residue well enough that later inspection is still possible.
5. Bring the board up on a current-limited supply or USB power meter before normal use.
6. Record the operator, date, board revision, alloy used, rework type, and any replaced part lot.

## Training Materials

Use these before doing independent rework on a live WILD board:

- Read the WILD assembly files for orientation and exact reference designators.
- Read the STM32 package section before replacing `U$6`.
- Read the Intan package and footprint pages before reballing `U$1`.
- Review the linked QFN and BGA tutorial videos before using hot air on dense boards.
- Pull the current Omnetics drawing or catalog entry before touching `S1` or `S3`, especially if the connector lot or finish has changed.

For training, the first Intan reball and the first Omnetics hand-solder job should be done on practice boards or spare parts before touching a live WILD board.

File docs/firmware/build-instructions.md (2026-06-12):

# Build Instructions

This page is the public build checklist for firmware contributors.

## Toolchain

- Keil MDK for the reference STM32 project.
- STM32CubeProgrammer for flashing and recovery.
- Git for tracking firmware and release assets.

## Build Flow

1. Open the firmware project in the configured IDE.
2. Select the correct target for the hardware revision.
3. Build the application image.
4. Archive the binary with hardware revision, date, and short commit identifier.
5. Flash directly for development or stage the image for microSD bootloader update.
6. Record the binary filename in experiment notes.

## Release File Naming

Prefer names that can be traced later:

```text
WILD_<revision>_release_YYYYMMDD_HHMM.bin
```

## Public Checklist

- Hardware revision tested.
- Bootloader compatibility verified.
- BLE discovery verified.
- SD formatting and recording verified.
- Closed-loop modes smoke-tested if changed.
- Data export and preprocessing verified on a short recording.

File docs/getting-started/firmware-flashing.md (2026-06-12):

# Firmware Flashing

WILD uses a bootloader plus application-image workflow. The first flash programs the bootloader; later firmware updates can be staged through the microSD card.

## First-time Bootloader Flash

1. Connect the 4-pin IO-USB cable, but do not connect the cable to the PC yet.
2. Short the DFU mode select pin to VDD.
3. Connect USB to the PC while holding the short.
4. Release the short after the device powers up.
5. Open STM32CubeProgrammer.
6. Flash the bootloader image from [Firmware](https://github.com/zifangzhao/Neurologger/tree/main/Firmware).

## Application Update from microSD

1. Format the microSD card from WILD_console.
2. Copy the application image to the card.
3. Insert the card into WILD.
4. Power the device.
5. Wait for the bootloader LED pattern to finish. The current guide notes that application upgrade takes about 10 seconds, depending on image size.

## Firmware References

- Current repository release images are in [Firmware](https://github.com/zifangzhao/Neurologger/tree/main/Firmware).
- WILD firmware reference projects use STM32 firmware sources and Keil MDK project files.
- Keep a record of the firmware image used for each experiment so analysis metadata can be traced later.

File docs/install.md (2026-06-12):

# WILD API Installation

## Requirements

- Windows 10 or later.
- .NET Framework 4.8.
- Visual Studio 2022 for development builds.

## Steps

1. Clone the repository:

   ```bash
   git clone https://github.com/zifangzhao/Neurologger
   cd Neurologger
   ```

2. Navigate to `Software/` and install the latest WILD console package.

## For Development

1. Open the WILD console solution in Visual Studio.
2. Restore NuGet packages and build.

## Dependencies

- Windows Bluetooth APIs.
- System.Windows.Forms.
- Microsoft.Win32.SafeHandles.

## Optional Runtime Files

- `dll_upfirdn.dll` - resampling backend.
- WILD BLE backend DLL, if required by the selected installer.

Place runtime DLLs in the same folder as the WILD console executable.

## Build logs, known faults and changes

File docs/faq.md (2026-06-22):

# FAQ

## Is WILD a replacement for wired acquisition?

WILD is designed for wireless and naturalistic experiments where tethered acquisition is limiting. The correct choice depends on channel count, runtime, signal quality, synchronization, and behavioral constraints.

## Is WILD a BLE telemetry system?

No. WILD is primarily a local-storage neurologger. High-bandwidth neural and multimodal data are recorded to the device microSD card. BLE is used for discovery, configuration, synchronization support, status, selected low-bandwidth preview, and control commands.

## What is the current recording scale?

The current open-source workflow is the 64-channel WILD system. Neuropixels-compatible and active-SPI-probe variants are higher-performance research targets and are separate from the current public release unless a release note explicitly states otherwise.

## How do I install the PC software?

The latest installer is available from the [latest GitHub release](https://github.com/ayalab1/Neurologger/releases/latest), with setup details in the acquisition guide.

## BLE connects, but recording does not start

The microSD card is the first item to verify. SD format and card compatibility are common causes when BLE connects but synchronization does not begin.

## Does WILD support TinyML?

WILD supports online inference of curated, experiment-specific models through validated release images. Runtime generic model loading is not part of the stable public workflow yet.

## How do I cite WILD?

Use the current citation guidance on the [Publications](publications/index.md) page. Until the manuscript is published, cite the repository or release record and include the WILD hardware revision, release image, WILD Console version, and analysis-script version.

## Where do new diagrams go?

Source diagrams are best kept editable where possible, with web-ready images exported into `docs/images/`. For readable architecture diagrams, Mermaid in Markdown is preferred.

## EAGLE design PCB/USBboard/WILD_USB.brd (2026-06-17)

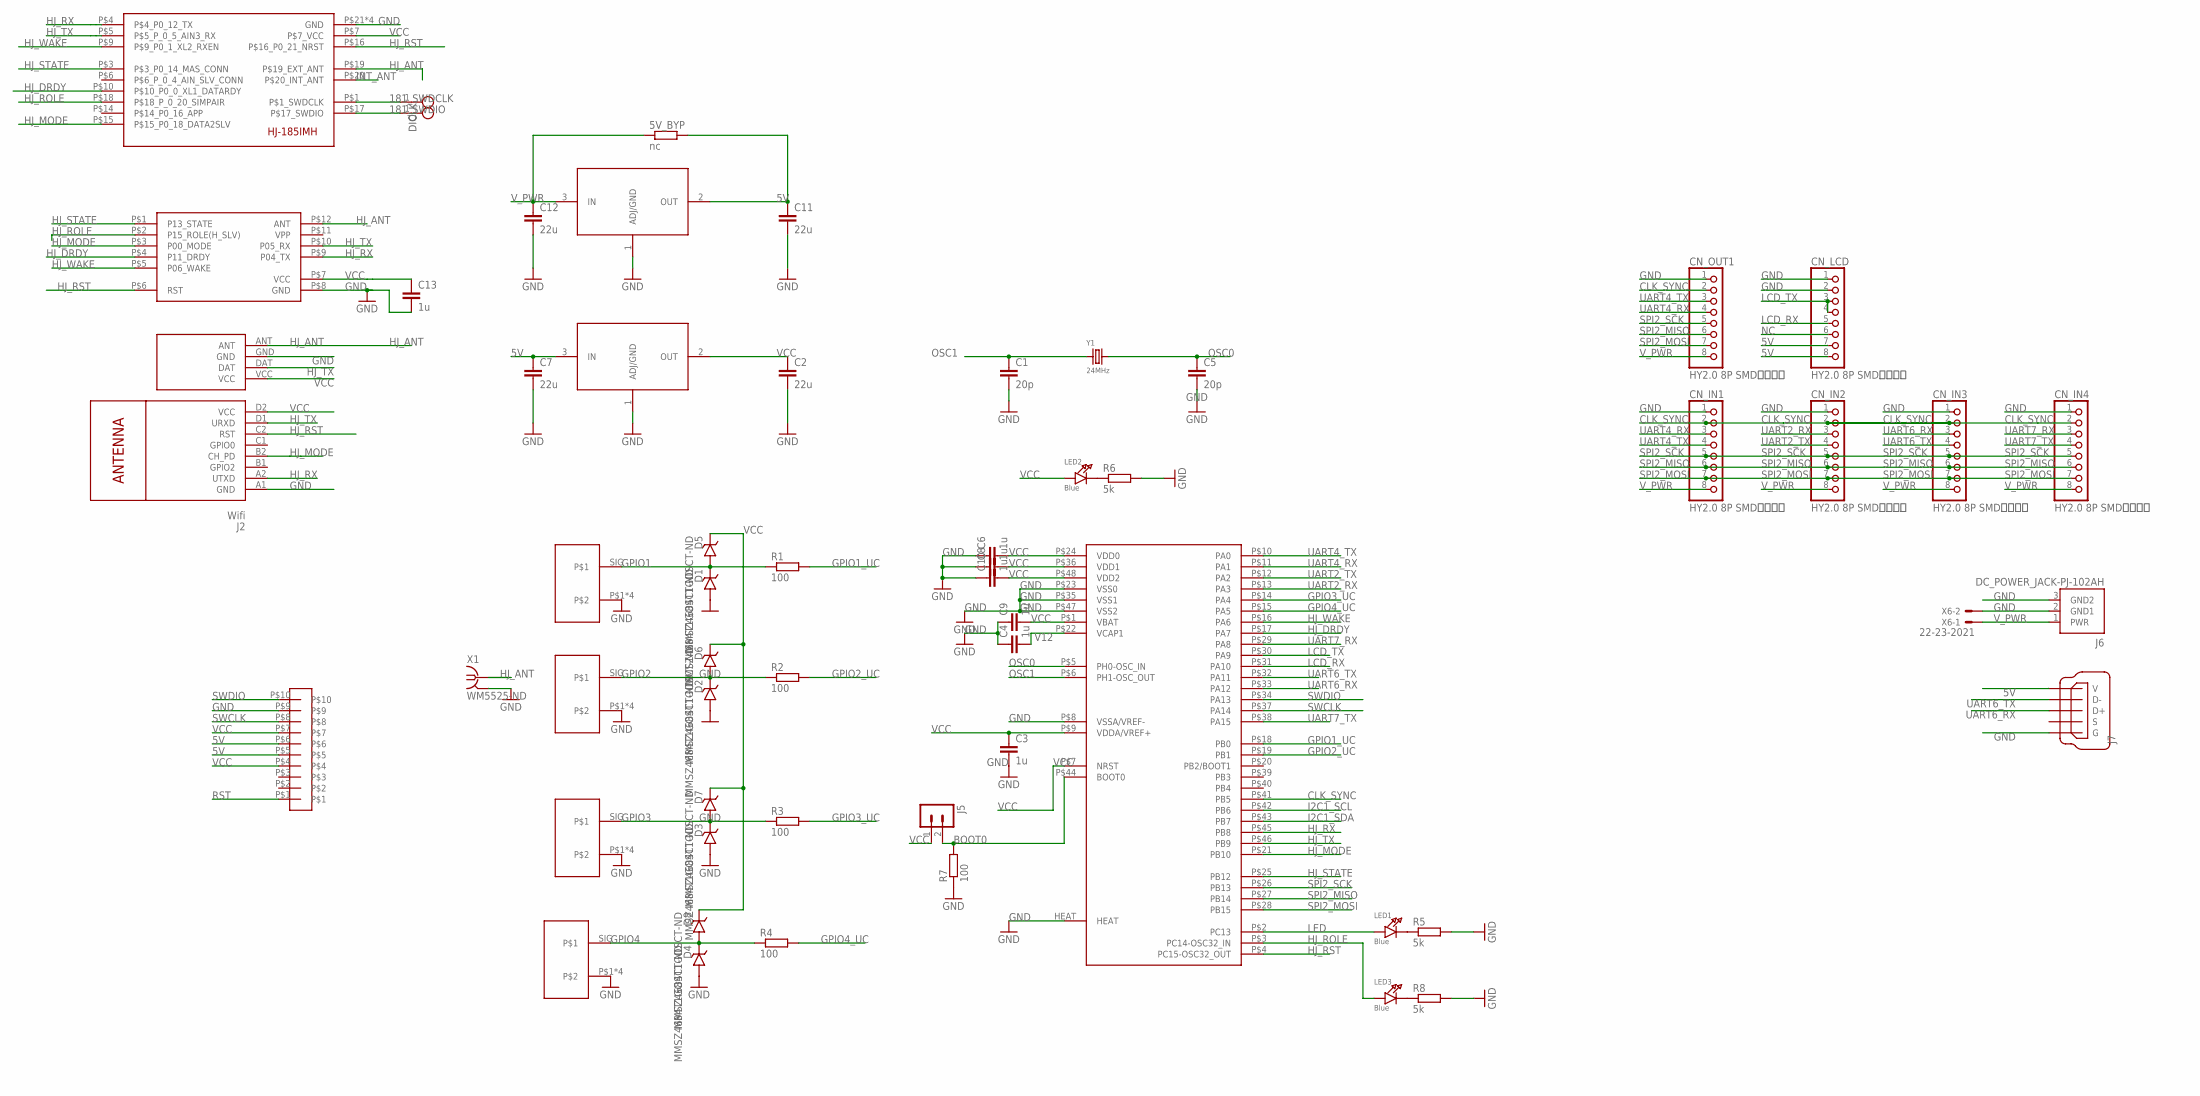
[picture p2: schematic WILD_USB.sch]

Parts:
5V_BYP: nc; R1206
C1, C5: 20p; C1206
C2, C7, C11, C12: 22u; C1206
C3, C4, C6, C8, C9, C10, C13: 1u; C1206
CLK: TESTPOINT_SMALL
CN_IN1, CN_IN2, CN_IN3, CN_IN4: HY2.0 8P SMD卧贴插座; JSTPH8
CN_LCD: HY2.0 8P SMD卧贴插座; JSTPH8
CN_OUT1: HY2.0 8P SMD卧贴插座; JSTPH8
D1, D2, D3, D4, D5, D6, D7, D8: MMSZ4684T1GOSCT-ND; SOD-123
DIO: TESTPOINT_SMALL
J1: Sub-GHz; SYN115
J2: Wifi; WIRELESS-WIFI-ESP-01
J3: 2*5P 2.54mm 双排母 母座; 2.54MM_2X5
J5: nc; JUMPER2
J6: DC_POWER_JACK-PJ-102AH; PJ-102AH
J7: J7; ZX62R-B-5P
LED1, LED2, LED3: Blue; CHIPLED_1206
R1, R2, R3, R4, R7: 100; R1206
R5, R6, R8: 5k; R1206
U1: STM32F413CHU6; UFQFPN48
U2: HJ580
U3: HJ_185IMHQFN; HJ_185IMH
U4: ADP3338AKCZ-3.3; SOT223
U5: nc; SOT223
X1: WM5525-ND; BU-SMA-H
X2, X3, X4, X5: BNC_8MM; BNC_V_8MM
X6: 22-23-2021
Y1: 24MHz; HC49UP

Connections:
5V: 5V_BYP.2, C7.1, C11.1, CN_LCD.7, CN_LCD.8, J3.P$5, J3.P$6, J7.1 (V), U4.3 (IN), U5.2 (OUT)
181_SWDCLK: CLK.1, U3.P$1 (P$1_SWDCLK)
181_SWDIO: DIO.1, U3.P$17 (P$17_SWDIO)
BOOT0: J5.2, R7.2, U1.P$44 (BOOT0)
CLK_SYNC: CN_IN1.2, CN_IN2.2, CN_IN3.2, CN_IN4.2, CN_OUT1.2, U1.P$41 (PB5)
GND: C1.2, C2.2, C3.2, C4.1, C5.2, C6.1, C7.2, C8.1, C9.1, C10.1, C11.2, C12.2, C13.2, CN_IN1.1, CN_IN2.1, CN_IN3.1, CN_IN4.1, CN_LCD.1, CN_LCD.2, CN_OUT1.1, D1.2 (A), D2.2 (A), D3.2 (A), D4.2 (A), J1.GND, J2.A1 (GND), J3.P$9, J6.2 (GND1), J6.3 (GND2), J7.5 (G), R5.2, R6.2, R7.1, R8.2, U1.HEAT, U1.P$8 (VSSA/VREF-), U1.P$23 (VSS0), U1.P$35 (VSS1), U1.P$47 (VSS2), U2.P$8 (GND), U3.P$21 (GND), U3.P$22 (GND), U3.P$23 (GND), U3.P$24 (GND), U4.1 (ADJ/GND), U5.1 (ADJ/GND), X1.2, X1.3 (2), X1.4 (2), X1.5 (2), X2.P$1, X2.P$2, X2.P$3, X2.P$4, X3.P$1, X3.P$2, X3.P$3, X3.P$4, X4.P$1, X4.P$2, X4.P$3, X4.P$4, X5.P$1, X5.P$2, X5.P$3, X5.P$4, X6.2
GPIO1: D1.1 (C), D5.2 (A), R1.1, X2.SIG
GPIO1_UC: R1.2, U1.P$18 (PB0)
GPIO2: D2.1 (C), D6.2 (A), R2.1, X3.SIG
GPIO2_UC: R2.2, U1.P$19 (PB1)
GPIO3: D3.1 (C), D7.2 (A), R3.1, X4.SIG
GPIO3_UC: R3.2, U1.P$14 (PA4)
GPIO4: D4.1 (C), D8.2 (A), R4.1, X5.SIG
GPIO4_UC: R4.2, U1.P$15 (PA5)
HJ_ANT: J1.ANT, U2.P$12 (ANT), U3.P$19 (P$19_EXT_ANT), X1.1
HJ_DRDY: U1.P$17 (PA7), U2.P$4 (P11_DRDY), U3.P$10 (P$10_P0_0_XL1_DATARDY)
HJ_MODE: J2.B2 (CH_PD), U1.P$21 (PB10), U2.P$3 (P00_MODE), U3.P$15 (P$15_P0_18_DATA2SLV)
HJ_ROLE: LED3.A, U1.P$3 (PC14-OSC32_IN), U2.P$2 (P15_ROLE(H_SLV)), U3.P$18 (P$18_P_0_20_SIMPAIR)
HJ_RST: J2.C2 (RST), U1.P$4 (PC15-OSC32_OUT), U2.P$6 (RST), U3.P$16 (P$16_P0_21_NRST)
HJ_RX: J2.A2 (UTXD), U1.P$45 (PB8), U2.P$9 (P04_TX), U3.P$4 (P$4_P0_12_TX)
HJ_STATE: U1.P$25 (PB12), U2.P$1 (P13_STATE), U3.P$3 (P$3_P0_14_MAS_CONN)
HJ_TX: J1.DAT, J2.D1 (URXD), U1.P$46 (PB9), U2.P$10 (P05_RX), U3.P$5 (P$5_P_0_5_AIN3_RX)
HJ_WAKE: U1.P$16 (PA6), U2.P$5 (P06_WAKE), U3.P$9 (P$9_P0_1_XL2_RXEN)
I2C1_SCL: U1.P$42 (PB6)
I2C1_SDA: U1.P$43 (PB7)
INT_ANT: U3.P$20 (P$20_INT_ANT)
LCD_RX: CN_LCD.5, U1.P$31 (PA10)
LCD_TX: CN_LCD.3, CN_LCD.4, U1.P$30 (PA9)
LED: LED1.A, U1.P$2 (PC13)
unnamed: LED3.C, R8.1
unnamed: LED1.C, R5.1
unnamed: LED2.C, R6.1
NC: CN_LCD.6
OSC0: C5.1, U1.P$5 (PH0-OSC_IN), Y1.2
OSC1: C1.1, U1.P$6 (PH1-OSC_OUT), Y1.1
RST: J3.P$1
SPI2_MISO: CN_IN1.6, CN_IN2.6, CN_IN3.6, CN_IN4.6, CN_OUT1.6, U1.P$27 (PB14)
SPI2_MOSI: CN_IN1.7, CN_IN2.7, CN_IN3.7, CN_IN4.7, CN_OUT1.7, U1.P$28 (PB15)
SPI2_SCK: CN_IN1.5, CN_IN2.5, CN_IN3.5, CN_IN4.5, CN_OUT1.5, U1.P$26 (PB13)
SWCLK: J3.P$8, U1.P$37 (PA14)
SWDIO: J3.P$10, U1.P$34 (PA13)
UART2_RX: CN_IN2.3, U1.P$13 (PA3)
UART2_TX: CN_IN2.4, U1.P$12 (PA2)
UART4_RX: CN_IN1.3, CN_OUT1.4, U1.P$11 (PA1)
UART4_TX: CN_IN1.4, CN_OUT1.3, U1.P$10 (PA0)
UART6_RX: CN_IN3.3, J7.3 (D+), U1.P$33 (PA12)
UART6_TX: CN_IN3.4, J7.2 (D-), U1.P$32 (PA11)
UART7_RX: CN_IN4.3, U1.P$29 (PA8)
UART7_TX: CN_IN4.4, U1.P$38 (PA15)
V12: C4.2, U1.P$22 (VCAP1)
VCC: C2.1, C3.1, C6.2, C8.2, C9.2, C10.2, C13.1, D5.1 (C), D6.1 (C), D7.1 (C), D8.1 (C), J1.VCC, J2.D2 (VCC), J3.P$4, J3.P$7, J5.1, LED2.A, U1.P$1 (VBAT), U1.P$7 (NRST), U1.P$9 (VDDA/VREF+), U1.P$24 (VDD0), U1.P$36 (VDD1), U1.P$48 (VDD2), U2.P$7 (VCC), U3.P$7 (P$7_VCC), U4.2 (OUT)
V_PWR: 5V_BYP.1, C12.1, CN_IN1.8, CN_IN2.8, CN_IN3.8, CN_IN4.8, CN_OUT1.8, J6.1 (PWR), U5.3 (IN), X6.1

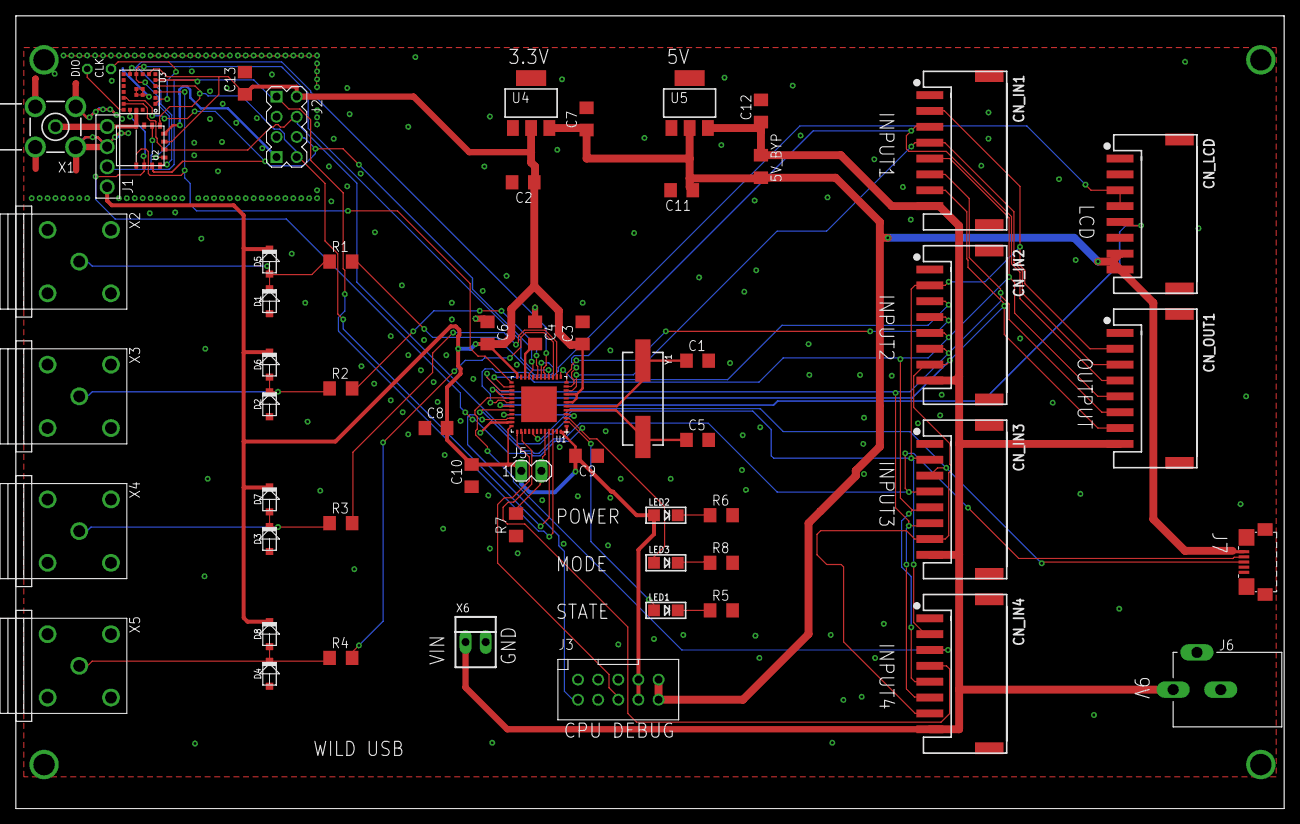
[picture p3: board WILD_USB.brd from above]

Board: 2 copper layers, 160.0 x 100.0 mm, 59 parts (0 on the bottom side), 47 nets.

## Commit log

2026-05-08 WILD V45 + console V3.2.1.0
    Added two way synchronization with continuous synchronization <10ms and drift detection
    PC continueous clock calibration
    Host-follower mode:Multi-logger sample-sample synced recording
    BLE reliability
    Record file management over BLE
    Improved SD download speed
    Automatic SDcard unmount in windows
2026-06-15 Use ephys sample image on homepage
2026-06-17 Refine WILD docs landing cards and hardware visuals
2026-06-17 Add fabrication docs and USB board package
    [WILD_USB.brd, WILD_USB.csv, WILD_USB.sch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]
2026-06-26 Add public soldering and rework SOP

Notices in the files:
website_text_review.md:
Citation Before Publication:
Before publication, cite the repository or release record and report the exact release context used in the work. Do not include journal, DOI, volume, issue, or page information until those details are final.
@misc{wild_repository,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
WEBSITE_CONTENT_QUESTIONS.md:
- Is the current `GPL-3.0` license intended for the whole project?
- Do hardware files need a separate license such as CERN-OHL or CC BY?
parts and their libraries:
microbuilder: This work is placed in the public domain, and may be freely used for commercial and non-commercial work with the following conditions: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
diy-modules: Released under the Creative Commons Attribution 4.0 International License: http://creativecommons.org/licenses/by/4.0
